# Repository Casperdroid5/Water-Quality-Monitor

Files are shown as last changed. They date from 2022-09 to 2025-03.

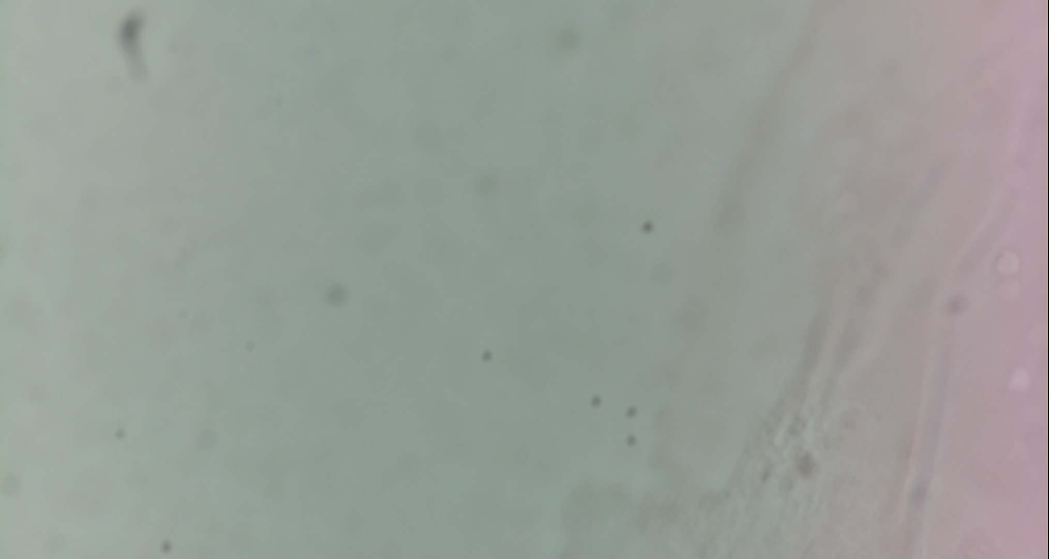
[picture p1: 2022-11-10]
Software/Camera/Test recordings/test.jpg

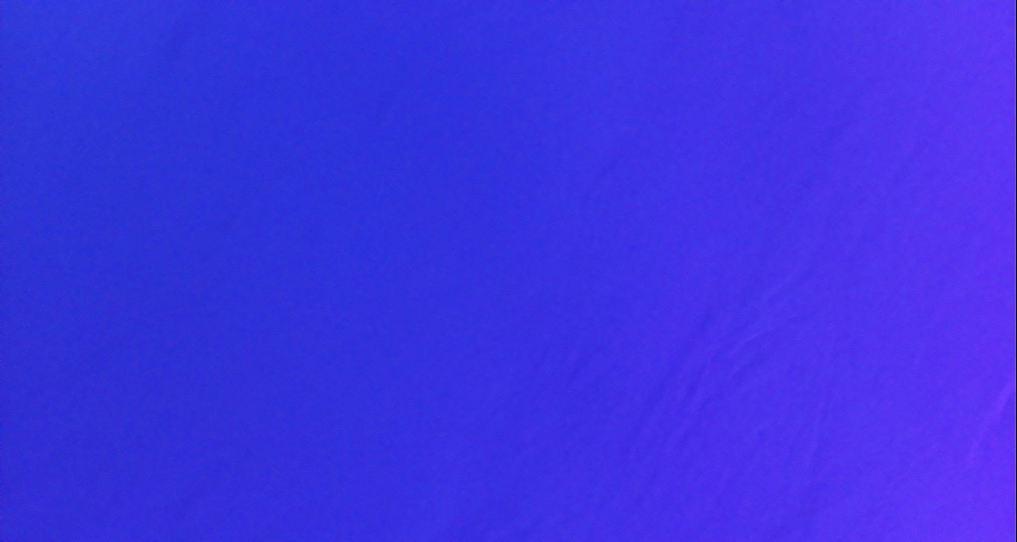
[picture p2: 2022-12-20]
Software/Camera/test3.jpg

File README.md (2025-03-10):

# Water Quality Monitor

This document outlines my contribution to the Water Quality Monitor project during my internship at the Health Concept Lab.

## Overview

The Water Quality Monitor utilizes a Raspberry Pi running Raspbian as the main controller and computer, along with a custom-designed PCB for circuit layout. Hardware control, GUI, and data processing are implemented using Python.

## Design Process

The design process involved selecting suitable hardware components, designing the PCB layout, and programming the firmware in Python.

1. **Hardware Selection**: Chose appropriate sensors, actuators, and electronic components to suit the needs of the clients setup.
2. **PCB Design**: Created a custom PCB layout to ensure optimal circuit connections.
3. **Firmware Development**: Developed the firmware using Python to enable hardware communication.
## Testing

Comprehensive testing was conducted to ensure accuracy and reliability.

1. **Hardware Testing**: Verified proper functionality of each hardware component on the printed circuitboard.
2. **Software Testing**: Thoroughly tested firmware for peripherals.

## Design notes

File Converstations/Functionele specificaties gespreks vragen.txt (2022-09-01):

1. Is dit een water kwaliteit monitor voor nu? -> het is een waterkwaliteit monitor
2. Hoe wordt de informatie gewonnen, via camera, maar hoe wordt dit geïnterpreteerd en in hoe verre is dit mijn taak? -> camera is belangrijkste, andere sensoren op i2c voor uitbreiding. ik hoef niet specifiek met de camera bezig. Beelden maken (foto's en video's) moet ik wel maken en verwerken. simpele foto of video maken door de microscoop, niets bijzonders verder.
3. De hoofdfunctie is water kwaliteit meten, maar wat zijn de subfuncties die deze hoofdfunctie in werking brengen?
4. Kunnen we samen gaan zitten voor de functionele specificaties?
5. Strokenplanner gebruiken, in combinatie met trello.
6. Na documentatie voor functioneel en technisch, blokdiagram maken (functie verbintenissen, input/ouput, power definities).

PCB functions: 
Doel voor camera: scherp beeld = Focus motor: driver, lens moet versteld worden of Moving magnet driver, voor scherpstellen/focus

Led driver voor camera verlichting (cn5711)

Pompmotor = driver voor pompmotor (misschien 3 motoren) één voegt water toe, ander stofje etc. 

Externe connectoren i2c (sparkfun connector molex?) 

Koelen en verhitten: moet flink wat stroom kunnen lopen (flinke kunnen stromen schakellen) 

Temperatuur sensor via i2c (al één gevonden) 
Flatcabel met daarin camera focusmotor stroom en i2c gecombineerd.

Één flatcable naar mijn printplaat (sensoren zijn i2c) 

Stepper motor chip (tmc2208)

Moving manget actuator driver (drv8838, vereist speciale pwm pinnen)

Hoofdvoeding wordt aangesloten aan mijn pcb, mijn pcb voedt de pi (v-in pin). 
Motoren en cool/warmte zal niet tegelijkertijd stroom verbruiken. Peltier verbruikt stroom terwijl sensoren meten.

Printplaat mag groter dan de pi (liever niet). Liefst 1 printplaat. Quad layer pcb.  Functionaliteit is belangrijk, hoeft niet draagbaar (wel optilbaar) te zijn (stroom)

Stacking pcb’s? flex pcb’s?

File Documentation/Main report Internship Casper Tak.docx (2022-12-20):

# POA Internship

Main report internship assignment Health Concept Lab

Student: Casper R. Tak

Studentnumber: 657313

Client: Rudie van den Heuvel

Coach: Jeroen Veen

High School: HAN Arnhem

Education: Embedded Systems Engineering

Date: 15-12-2022

# Preface

After attending both the S3 and S4 projects at the Health Concept Lab (HCL) at the HAN, I decided that this would also be a great place to do my internship. Since I have some learning goals left from my S4 project, I would like to finish those in my internship period. The goals I Have set are as follows:

- Improving and applying my planning skills to create more structure in my work approach
- Exploring and improving even further on PCB design by designing a PCB with KiCad V6
- Improving my programming basics and skills withing the language C, C++ and Python
- Explore and expand my horizon

The assignment that will allow me to get to these learning goals will be the fluid analysing device project. This project will focus on getting a better, smaller version of the fluid analysing device that was build by the S6 project students from previous years. The project is developed by Jeroen Veen, who is therefor my client.

This system will eventually be used as a mean to analyse water quality. Since people use a lot of medicine, especially since they get older and older, the urine and defecation contains medicine remains. This results in water getting polluted with these remains and that is harmful for organisms. The goals in the future will be to create a portable device that can easily and continuously monitor the water. Even further in the future the device will not only be used for fluid analysing but also recursive testing for (multiple) deceases.

# Motive

My interest in health and care have grown exponentially since my S3 project. I got interested in almost anything health care technology related. I got into contact with Rudie van den Heuvel, who told me that the health concept lab was still looking for students that could help with several project including the water monitoring system. He told me about the possibilities of growing with my PCB and Python skills and this is what got me motivated to join the HCL. I think the health concept lab and it teachers are able to provide me with the help and knowledge I seek to gain.

# Companies and individuals involved

Jeroen Veen is the project leader. He will be guiding me mostly through all the ESE related questions, regarding programming. Since Jeroen is the project leader and the client, I will be working very closely to him.

Rudie van den Heuvel is a IPD teacher and knows a lot about materials, mechanics and designing in general. He may be able to provide me with knowledge on how to approach this project and whenever I want to do something with materials, he can assist.

Health Concept Lab is the lab that has been created around 3 years ago. The goal of this lab is to create a pool of knowledge on health on both mechanical as electrical ground. The lab is populated by students from S3 and above and there some teachers, who are well known in the subjects, as well.

HAN teachers can be consulted as well. Johan Brussen or Francesco Ursino for example are well known with power electronics. They can help me when it comes to supplying bigger loads with power. Other ESE or ELC teachers can also be of help. For EMC I can probably go to Ivo van Diemen De Jel.

# Main and sub questions

The soul reason of creating this POA is to gain an understanding of the project, it’s size and the required approach to work as efficient as possible. By knowing what is expected, what is not, and how I think I can approach things, it should be possible for me to create a planning.

To get a understanding of the project’s size and the current challenges, I need to know what the problems are.

Problem: there is currently no all in one compact and functional driver board for the device.

# Goal and end product

The goal is to create a water analysing device. My goal would be to create a printed circuit board along with software for the raspberry pi that will control the monitoring system and retrieve all the data collected by it.

# Theory

See OneDrive documents.

I’m going to approach this project via the V-model

# Schedule

See schedule document.

# Design

Functional specifications
# | MoS CoW | Description

F1 | M | The device is collecting data with the biosensor setup
F1.1 | M | The device can detect particles
F1.2 | M | The device has a light source that provides sufficient light for the camera
F2 | M | The device can control the temperature of the examination chamber
F2.1 | M | The device can heat the examination chamber
F2.2 | M | The device can cool the examination chamber
F2.3 | M | The device can measure the temperature of the examination chamber
F3 | M | The device can manipulate fluid movement
F3.1.0 | M | The device can add fluids and remove fluids from the examination chamber
F3.1.1 | S | The fluid should be able to be moved forward and backwards.
F4 | M | The device is able to decontaminate the examination chamber
F5 | M | The device needs to be able to connect to external sensors
F6 | M | The device must be able to be carried by men
F6.1 | S | The device should be as small as possible
F6.2 | S | The device should be as light as possible
F6.3 | W | The device will not be battery powered

Technical Considerations
Part | (Expected) Function | Pros | Cons | Notes
Raspberry Pi 4 | Main computer | All in one computer, good documentation, good software support | Chip shortage creates vulnerability for supply chain | The compute model 4 is not an easy alternative since there is no build in camera connector. The Raspberry Pi 4 model B seems the most suitable
TPS61158 | LED driver | Flexible digital and pwm brightness control, 100:1 pwm dimming ratio, soft start build in | Datasheet unclear if there is a switching value of 750 Mhz or Khz | Mistakes in datasheet it seems, wrong frequency ratings
TPS6106x | LED driver | Pwm brightness control, digital brightness control, 1mhz fixed switching frequency | Made for multiple leds it seems, only 80% efficient | led disconnects during shutdown
TMC2209 | Stepper driver | High quality, good documentation | Not yet found, maybe over specked
ST L297 | Stepper driver | Reputable brand, low cpu usage | Expensive
Tmc2130 | Stepper driver | The flag ship version of the tmc series | Expensive and overkill
Tmc2208 | Stepper driver | Just as good as the 2209 | higher impedance and so lower output amperage than tmc2209. It also has less features than tmc2209
DRV8870 | H-bridge | Is able to supply 3.6A of current, enough for the peltier module most likely | Not the best option, a higher current version (6A) would have been ideal: DRV8874
IRL540SPBF | High load switching mosfet (logic level) | A logic level high mosfet that can handle very high currents (20A) | A little expensive
TPS61169 | LED driver | LED current can be set with resistor
TPS92360 | LED driver | LED current can be set with resistor | | Seems the same driver as the tps61169
P82B96 | I2C ESD protection IC | Galvanic separation of i2c lines which results in high esd level protection. One package saves all | A little more complicated possibly than using passive components. Expensive.

Technical specifications
# | MoSCoW | Description

T1 | M | A Raspberry Pi will be used as the computer and controller
T2 | M | The Raspberry Pi will connect to a PCB hat (PI-HAT)
T3 | M | The device will use a camera connected directly to the pi via a flat cable to take pictures and videos
T.3.1.0 | M | The camera will be stationary, the lens itself will move
T3.1.1 | M | The device will be able to focus and reposition the lens via motors or moving magnets
T3.1.2 | S | When using magnets, the drv8838 should be utilized
T4 | M | The device will have a LED to create light for the microscope
T4.1 | S | The led driver that should be utilized is the cn5711
T5 | M | There will be stepper motors used
T5.1 | S | The motors should be chosen according to the required strength
T5.2 | S | The motor resolution should be below x degrees
T6 | C | Some motors and sensors could be attachable via connectors
T6.1 | S | All connectors should be standard (nonproprietary)
T7 | M | The device will cool the examination chamber with a Peltier module
T7.1 | M | The Peltier module must be actively cooled to function and prevent damage
T7.2 | M | The device will heat the examination chamber via resistive heati
T8 | S | A flat cable should connect the sensors and motors data to the PI-HAT
T8.1 | C | The PI-Hat should distribute power to all devices including the Raspberry Pi
T8.2 | W | The PI-HAT will not have any LEDs or status indicators
T8.3 | C | The PI-HAT may provide a fan connector to cool the Raspberry Pi

# GUI

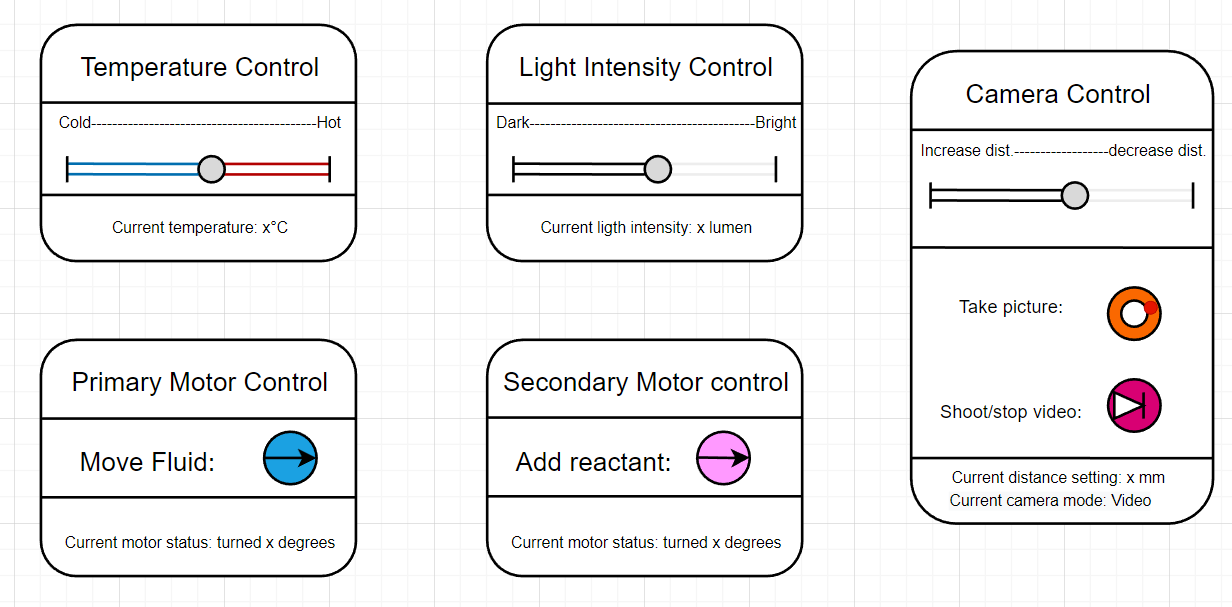
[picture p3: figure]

# Statemachine

State diagram

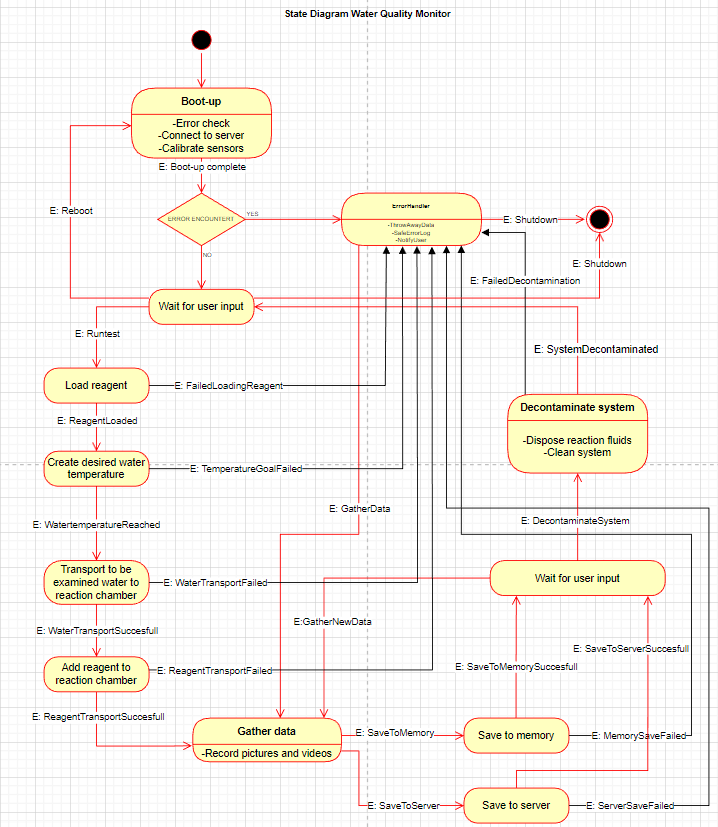
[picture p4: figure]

Use Case Diagram

System Architecture

Kesselring

# KiCad

## Why KiCad6?

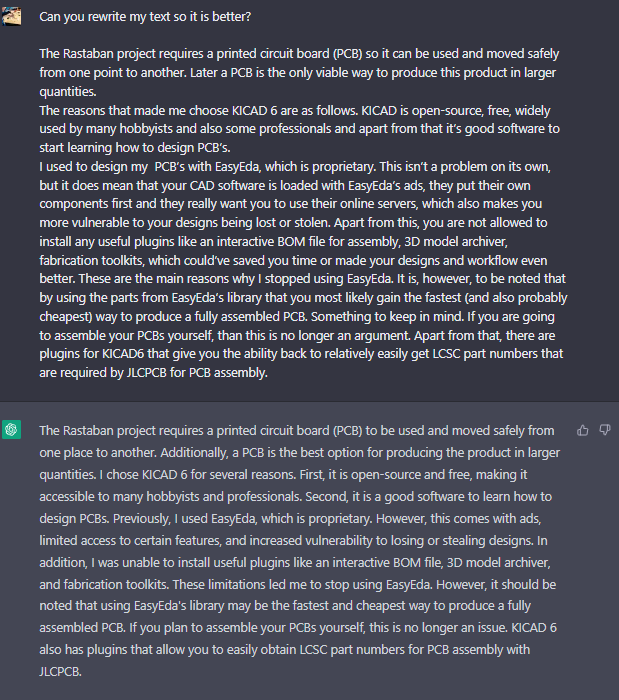
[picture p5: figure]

The Rastaban project requires a printed circuit board (PCB) to be used and moved safely from one place to another. Additionally, a PCB is the best option for producing the product in larger quantities. I chose KICAD 6 for several reasons.

First, it is open-source and free, making it accessible to many hobbyists and professionals. Second, it is a good software to learn how to design PCBs. Previously, I used EasyEda, which is proprietary. However, this comes with ads, limited access to certain features, and increased vulnerability to losing or stealing designs. In addition, I was unable to install useful plugins like an interactive BOM file, 3D model archiver, and fabrication toolkits. These limitations led me to stop using EasyEda. However, it should be noted that using EasyEda's library may be the fastest and cheapest way to produce a fully assembled PCB. If you plan to assemble your PCBs yourself, this is no longer an issue. KICAD 6 also has plugins that allow you to easily obtain LCSC part numbers for PCB assembly with JLCPCB.

## Plugins

To create an even better PCB and make my workflow easier, I downloaded a few plugins. The plugins I downloaded are as follows:

Name | Function | Download location
KiCAD JLCPCB tools | This plugin allows you to search the JLCPCB parts database, assign LCSC article numbers to your parts, generate production files for JLCPCB and much more. | https://github.com/Bouni/kicad-jlcpcb-tools
Interactive HTML BOM | This plugin generates convenient BOM listing with ability to visually correlate and easily search for components and their placements on the pcb. | Build into KICAD6
PCB action tools | Annular Ring Checker, Snap Selected Footprint(s) to Grid, Fabrication Footprint Position, Move Selected Drawings to chosen Layer, Export pcb technical layers to DXF, Checking 3D missing models | Build into KICAD6
Archive 3D models | Copies footprint models to the project local subfolder and remaps all the links within the used footprints. | Build into KICAD6
Place Footprints | Arrange sequentially numbered footprints or footprints from multiple hierarchical sheets in linear, circular or matrix arrangement. This plugin works on footprints already present in the layout, so that layout and schematics stay in sync. | Build into KICAD6
Round Tracks | Algorithmically smooth tracks in a predictable manner. Useful for flex PCBs, or just because it looks cool. | Build into KICAD6
Length matching | Track Length Calculator | Build into KICAD6
Freerouting | Auto router for Kicad. It draws all the connections between components for you. Be warned: Auto routing should never be used carelessly, always check the results. | Build into KICAD6 (requires Java)

## How to learn KICAD6

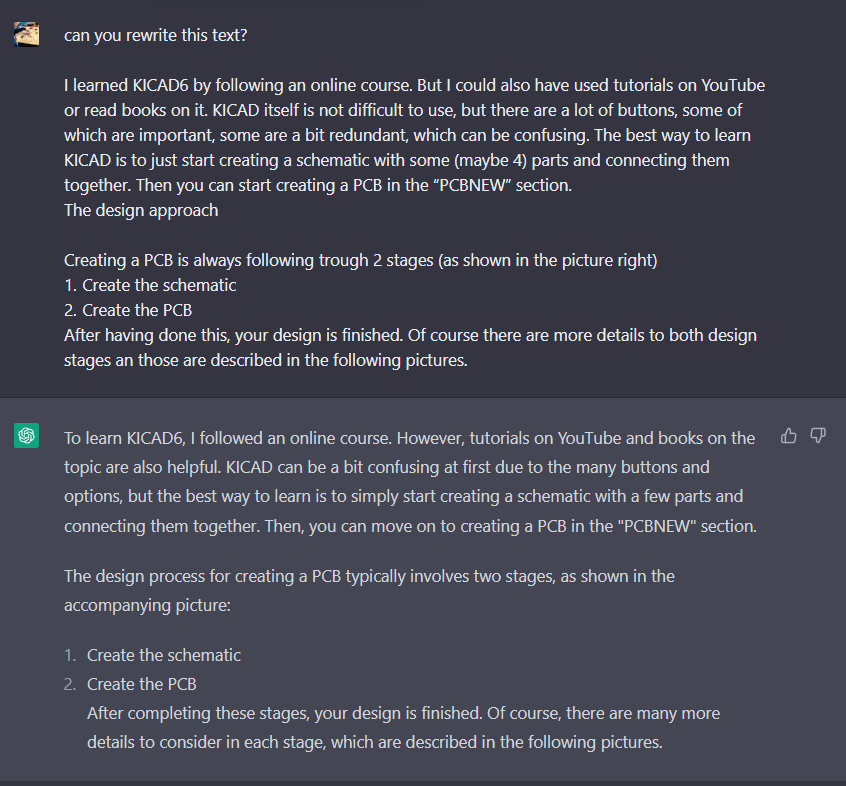
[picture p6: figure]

I learned KICAD6 by following an online course. (https://techexplorations.com/so/kicad-like-a-pro-3rd-edition/) But I could also have used tutorials on YouTube or read books on it. KICAD itself is not difficult to use, but there are a lot of buttons, some of which are important, some are a bit redundant, which can be confusing. The best way to learn KICAD is to just start creating a schematic with some (maybe 4) parts and connecting them together. Then you can start creating a PCB in the “PCBNEW” section.

## The design approach

Creating a PCB is always following trough 2 stages (as shown in the picture right)

1. Create the schematic

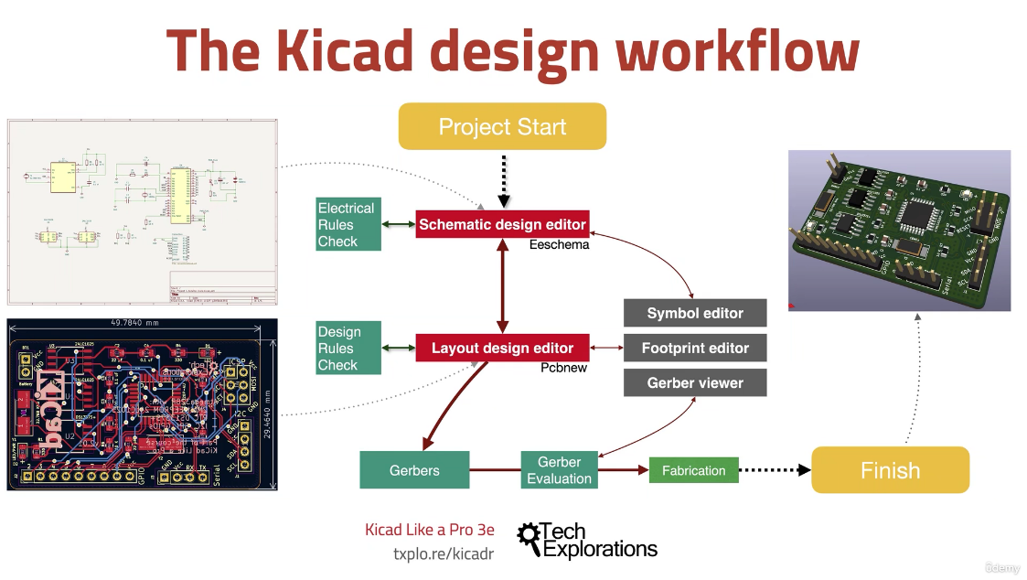
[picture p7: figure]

2. Create the PCB

After having done this, your design is finished. Of course there are more details to both design stages an those are described in the following pictures.

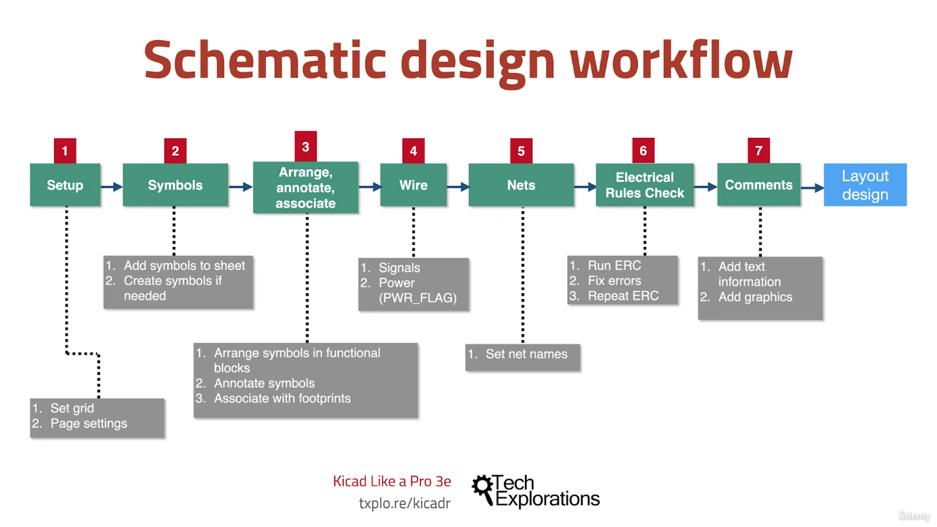
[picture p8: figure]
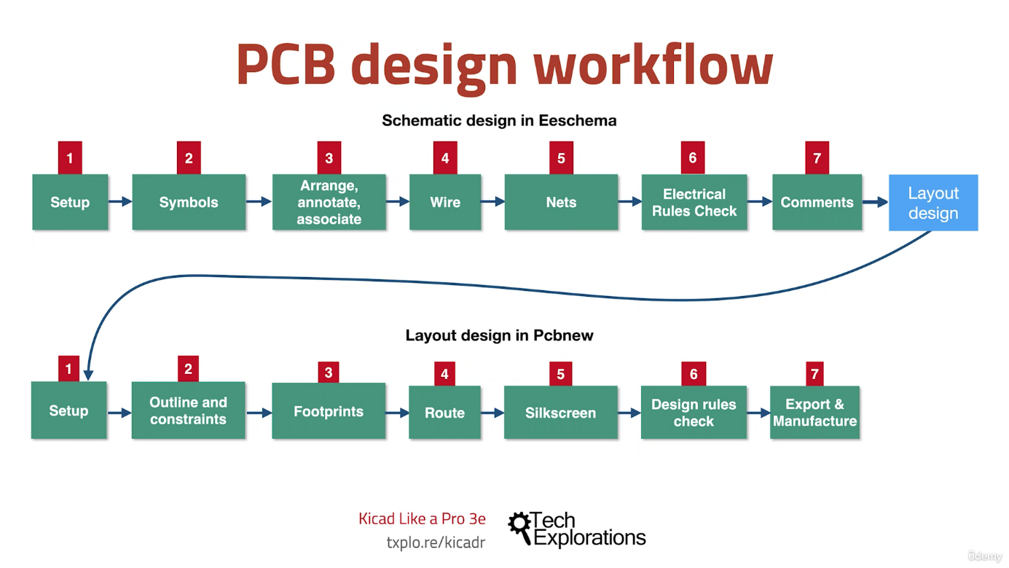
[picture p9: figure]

# System Components

## Microscope led

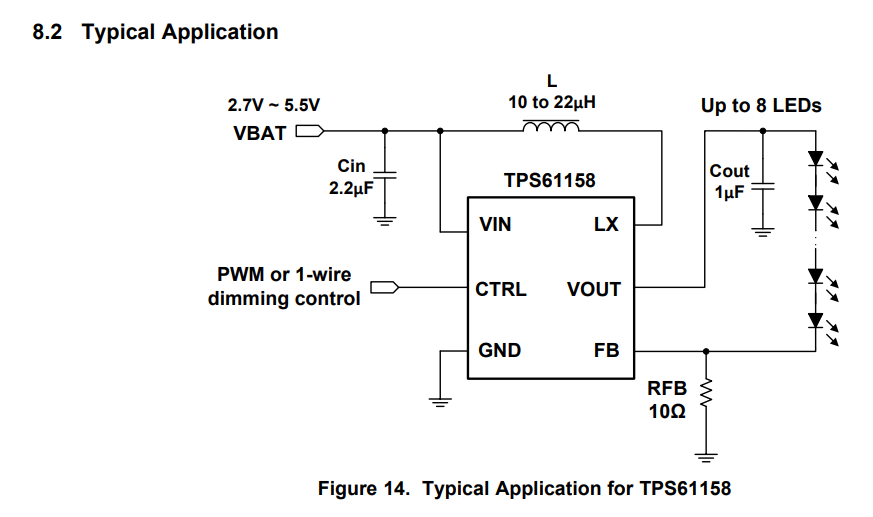
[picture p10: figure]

The input capacitor is to filter ripples from the power source and is there to function as a tiny buffer. The output capacitor is responsible for delivering current to the leds when the required current cannot be drawn continuously from the IC itself due to switching or power supply reasons. The inductor is there to function within the boost circuitry and has a high influence on the ripple and on maximum current and efficiency.

It is important to follow the pcb layout recommendations to avoid unsuspected behaviour due to unwanted resistance or capacitances.

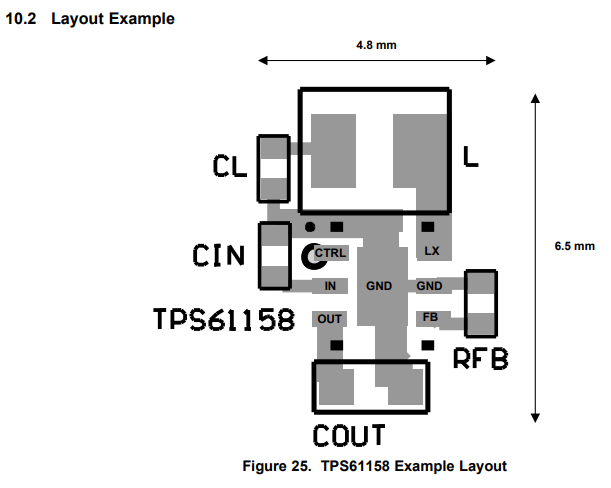
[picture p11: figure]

### Testing plan

When making a video or taking a picture of the reaction chamber, it is important that the LED light has a switching frequency that is higher than the shutter speed of the camera. If this is not the case, it could be that the image will appear to be darker or completely dark and that flickering will occur while recording a video. Therefor we need to know all shutter speeds of the camera and then we need to find what frequencies we need to drive the LED with, especially when dimming the light.

Our expected shutter speed: 60

Minimal shutter speed: 300usecs (https://forums.raspberrypi.com/viewtopic.php?t=323983)

Python control camera: https://raspberrypi.stackexchange.com/questions/99304/shutter-speed-and-exposure-time-of-picamera

About shutter speed and fps: https://camerajabber.com/what-shutter-speed-for-filming-moving-subjects/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,What%20is%20this%3F&text=Therefore%20if%20you%27re%20shooting,speed%20should%20be%201%2F120th.

## Driver circuit decision table

Nr. | Functionality | 1 | 2 | 3 | 4 | 5 | 6 | Points | Weightfactor
1 | Dim the led without visible flickering | - | 1 | 1 | 1 | 1 | 1 | 5 | 5
2 | Provide enough power to fully brighten LED | 0 | - | 0 | 1 | 1 | 1 | 3 | 3
3 | Enough brightness levels | 0 | 1 | - | 1 | 1 | 0 | 3 | 3
4 | PWM and digital control | 0 | 0 | 0 | - | 0 | 1 | 1 | 1
5 | PWM only control | 0 | 0 | 0 | 1 | - | 1 | 2 | 2
6 | Highest energy efficiency as possible | 0 | 0 | 0 | 0 | 0 | - | 0 | 0

We later concluded that it was rather difficult to get our hands on the chips we wanted to use. This is why we chose to go with the CN5711 driver. This one is widely available on LCSC, AliExpress and similar shops.

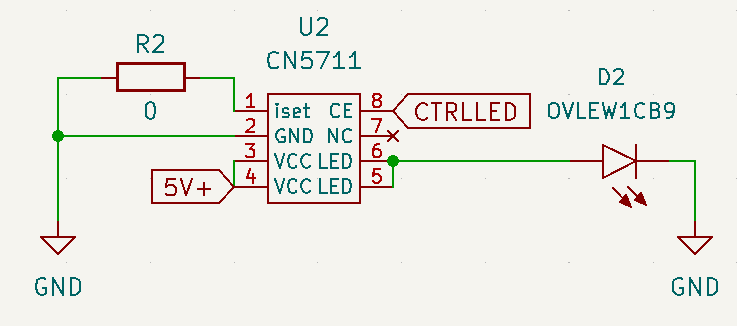
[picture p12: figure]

The driver was used in the testing setup for the LED. We never intended to use this chip since I didn’t feel comfortable investing in a “no name/brandless” chip that may become obsolete sooner than later. However for this prototype it is sufficient. Driving the chip is done via a PWM signal, which is not proprietary, the code will always stay the same even with a new driver. R2 may be set if current limiting the driver is desired.

## Stepper motor driver

2209 and 2208 have the same pinout, this should mean that they are interchangeable when it comes to the footprint on the pcb.

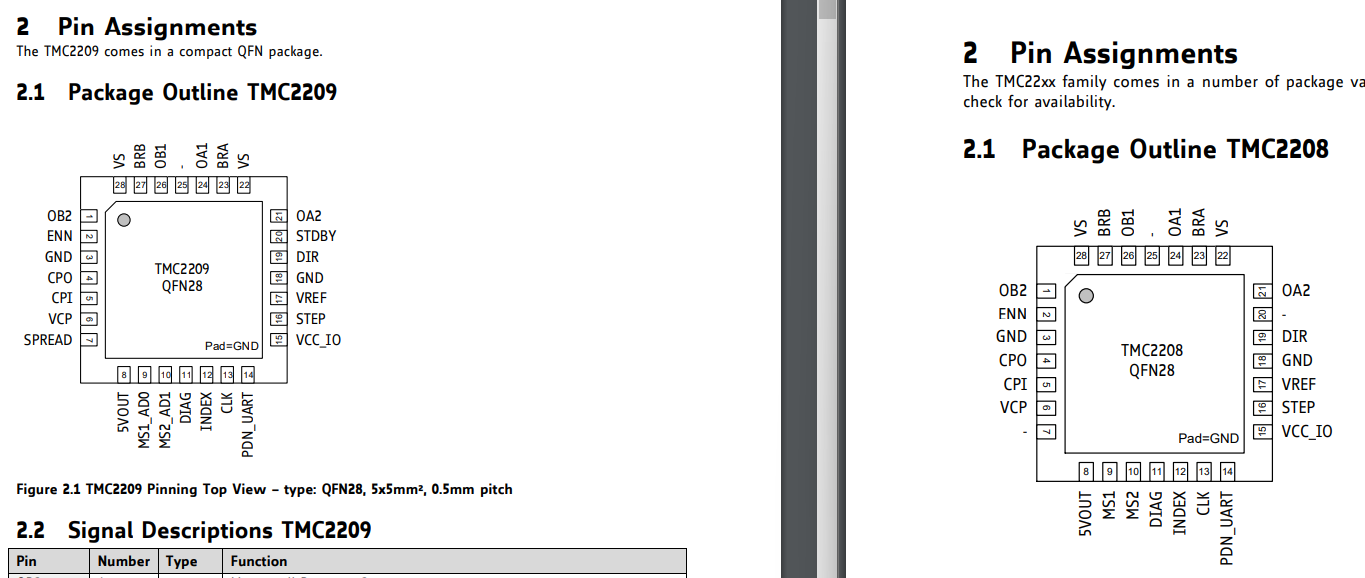
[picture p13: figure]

For layout considerations check chapter 19 of the tmc2208 datasheet.

### Later findings

The TMC2209 is the definitive replacement of the TMC2208 and TMC2130, so there is no good reason to keep using the depreciated TMC2208 in further designs.

### Micro stepping

Normally a stepper motor has 200 steps per complete revolution. Micro stepping can give you up to 51200 steps per complete revolution (depents on the motor of course) or 1/256 steps.

Benefits: improves noise levels and motor smoothness/accuracy and could improve energy effiency.

Drawbacks: decreases torque (especially at higher speeds) which could lead to stalling (some drivers can change stepping modes accordingly to speed).

source on Micro stepping https://www.youtube.com/watch?v=G8oGa2mawKk&t=68s

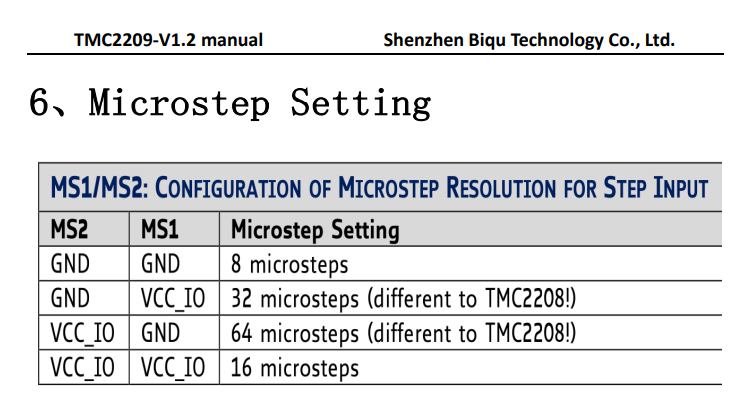
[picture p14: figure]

### UART on the TMC2209

Using the UART function of the TMC2209 we gain control many new functions including:

- Access to the control register
- Programmable 256 uStep sequencer
- Pulse generator
- SpreadCycle
- StealthChop
- Access to OTP

It is be possible to remove the STEP and DIR connections if we use UART to control one motor.

### UART Problem with multiple drivers

When connection multiple drivers you are able to read/write commands to the drivers individually using the same bidirectional line:

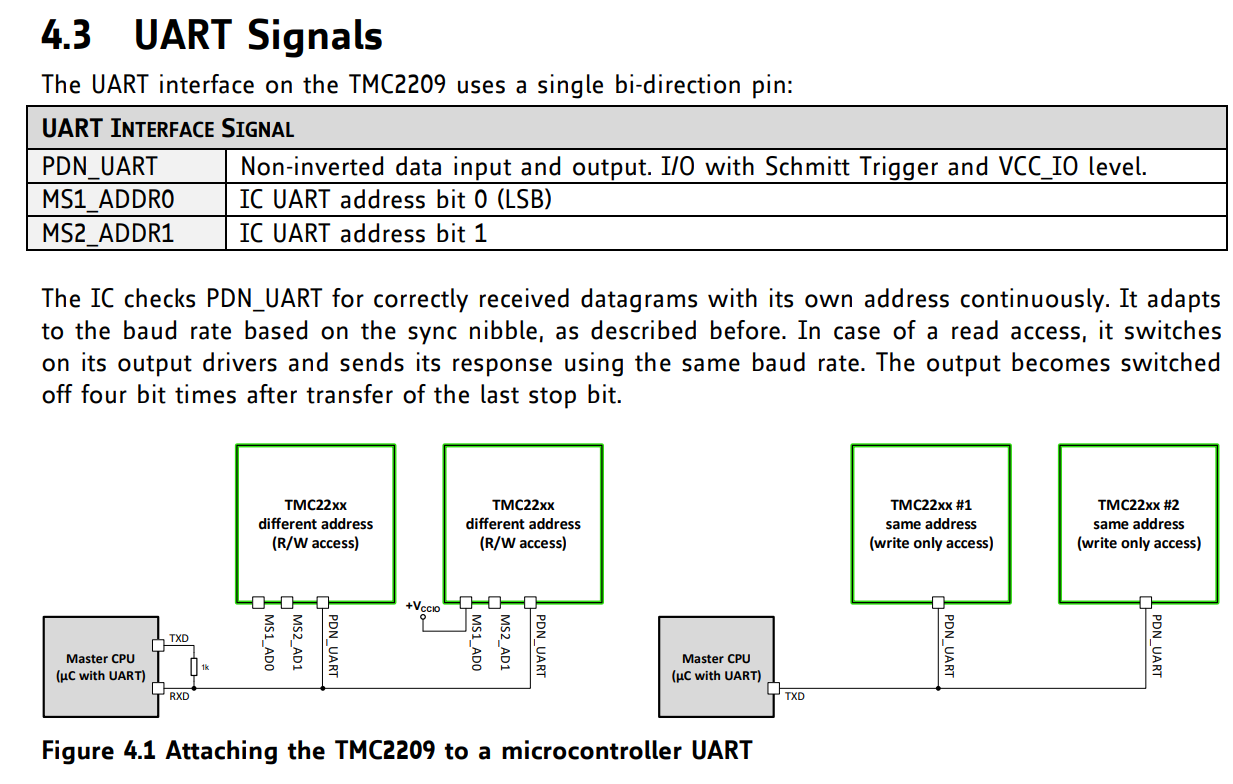
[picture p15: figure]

Strangely enough I not figure out why the above configuration did not work.

I configured one driver to be 01 and the other 00 by connection the ms1 and ms2 to GND and VCC the way it was shown in figure 4.1 above. Somehow I always get this message:

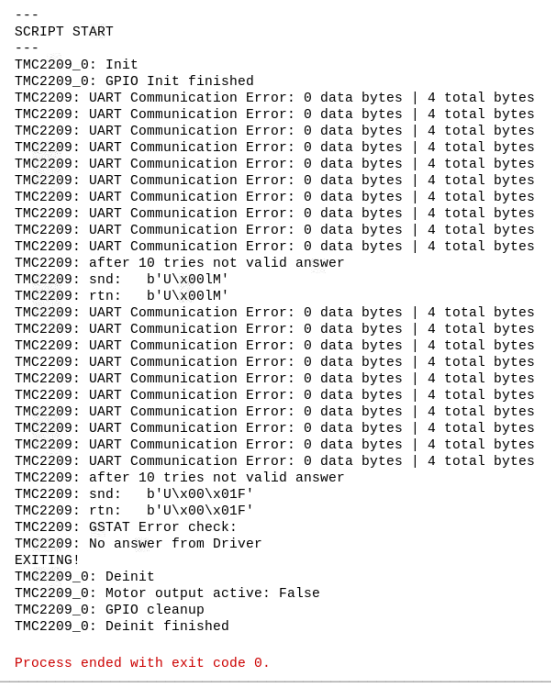
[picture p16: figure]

These are the configurations I tested:

| PDN UART | TMC software address settings | Result | Additional notes
TMC driver A | Connected to RX | 1 | Functional | Changing one address to 0 also makes it NOT functional
TMC driver B | Floating | 1
TMC driver A | Floating | 0 | Functional
TMC driver B | Connected to RX | 0
TMC driver A | Connected to RX | 0 | NOT Functional
TMC driver B | Floating | 1
TMC driver A | Floating | 0 | NOT Functional
TMC driver B | Connected to RX | 1

Conclusion: The driver UART control only works if there is one driver connected to RX and assigned address to this driver is selected in software (according to the ms1 + ms2 settings you chose). You can however use 2 drivers if you go with the “more than 4 drivers solution” which Trinamic provided. This could be achieved with transistors I suppose.

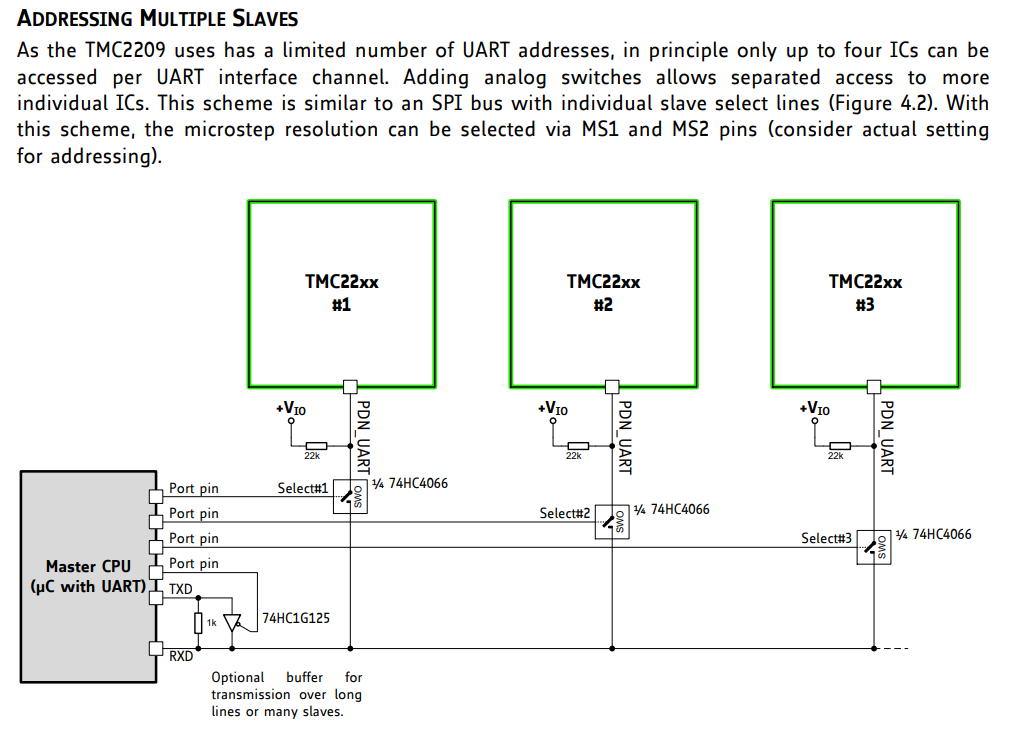
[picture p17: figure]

If reading from the driver is not required, using the write only function as seen in figure 4.1 of the datasheet is a viable option. This way we only need to use n+1 pins of the raspberry pi to control the motors, where n increases with every driver added (enable pin). This would treat all steppers as the same and would control them using the enable pin and sending data over the RX pin.

Configuration (test script 05: vactual.py) RX and TX are flipped on the picture:

This is what a successful transmission, with a few rotations and direction changes should look like.

When zoomed in it is clear that the TX deviates from the RX line data.

Further inspection shows that it does sometimes match the RX line

It is however always the case that TX continues sending after RX is done with a package.

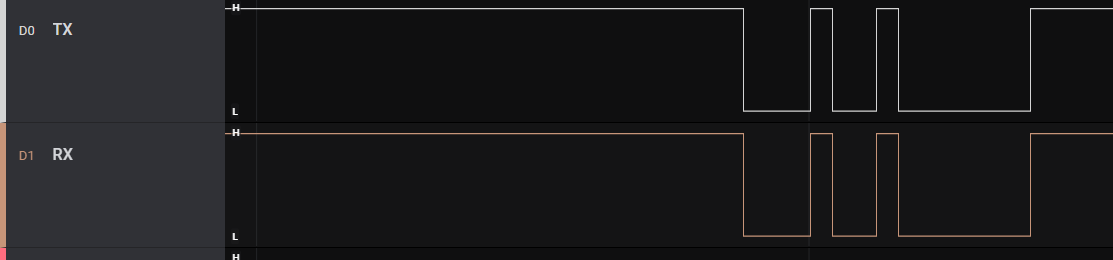
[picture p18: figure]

It is however always the case that TX continues sending after RX is done with a package.

Using these settings (test script 06: multiple drivers.py) RX and TX are flipped on the picture:

This is what a unsuccessful transmission looks like:

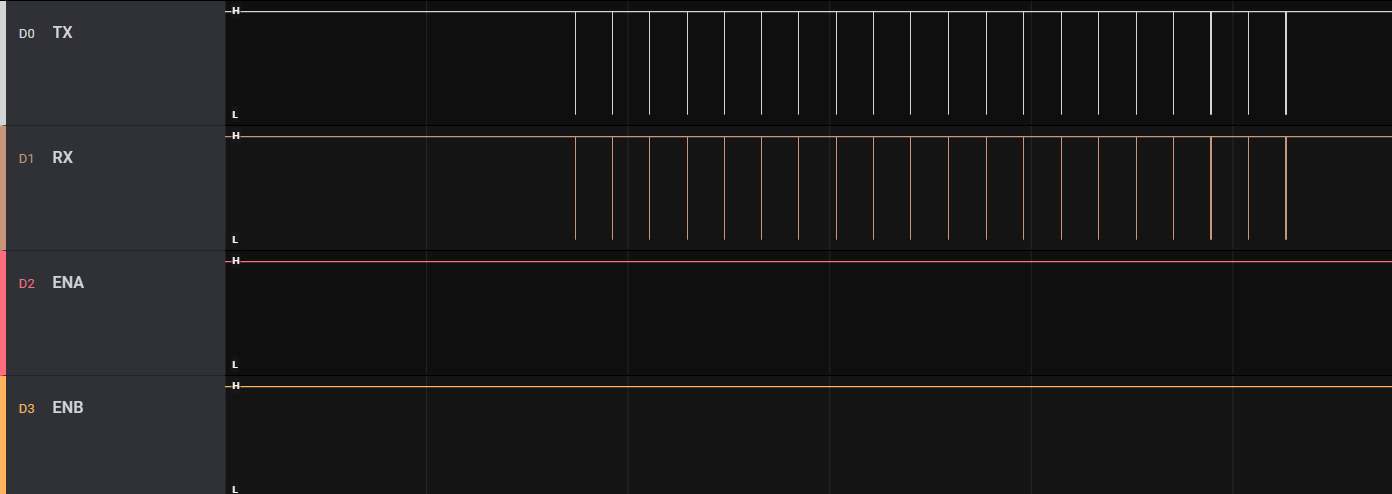
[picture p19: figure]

When zoomed in it seems that TX receives exactly the same information as it sends out. While, as stated earlier, it is expected that TX sends more data after RX is finished.

### Conclusion multiple drivers UART error:

I can conclude that somehow TX is getting the same information as it sends out on the RX line.

Fix found by Thomas Ijsseldijk: lowering the TX resistor to 500ohms increases the voltage available for the IO of the TMC driver which results in the TMC being able to read the signal. It appears to be very important to choose the right resistor value. It is now possible to control the stepper motors via UART. This reduces the pins required on the raspberry pi with 7 pins (removing all step and dir pins)

The final configuration for the stepper motor drivers is as following:

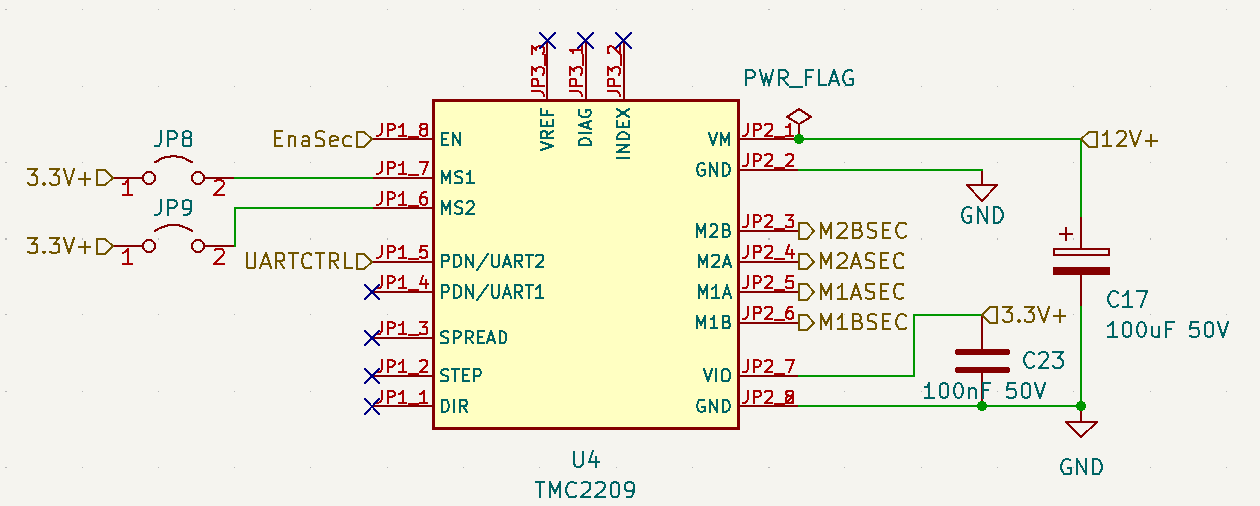
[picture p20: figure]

We decided to go with the TMC2209 and we operate it in UART mode only. This means we need to connect to PDN UART and use one enable pin per driver to select it.
Thermal Control

Thermal control will be in charge of providing energy and controlling all thermal regulating components of the Water Quality Monitoring (Rastaban) device fluids.

### The modules

The Thermal control consists of three power components:

1. Power Resistor
2. Peltier module
3. Fan (for peltier)

These components are here to increase or lower the temperature of fluid that would be examined. The first two modules will be drawing very high currents (2A and higher) and therefore these powerlines need to be controlled and protected with care.

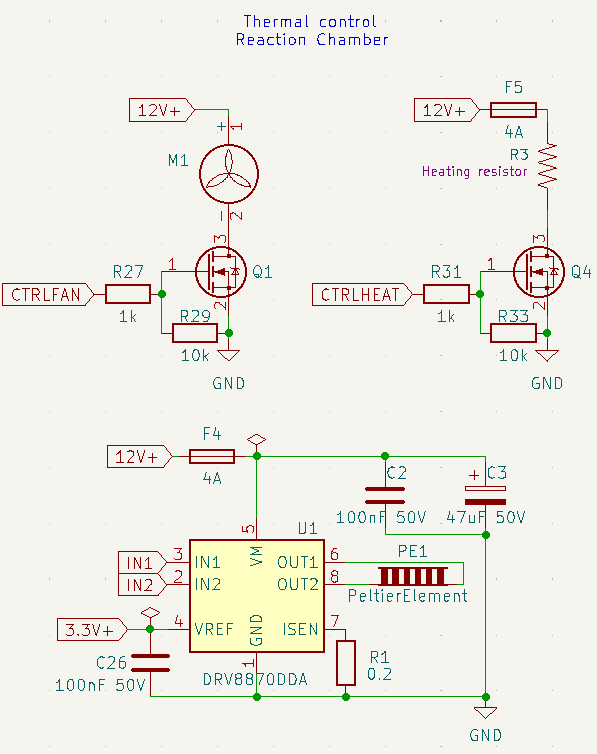
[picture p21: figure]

### The circuit

To control and protect the module and PCB from damage we need to building some passive protection. That’s why I chose some fuses that are roughly 1.25 times the value of the maximum current the module is supposed to use. When this value Is exceeded, the fuse will “blow” and the current will stop flowing.

The power mosfet used is the PMV15ENE. This NPN mosfet is designed to be controlled by a 3.3V logic level signal, which the raspberry pi uses as well. The mosfet is able to switch 6A and that’s why the component may seem overspecced. However, by using a higher current mosfet (lower RDS-on) there is higher efficiency because less energy is converted into resistive energy (heat). The component will also have a longer lifetime expectancy. Apart from this it also means there are no extra cooling components (heatsinks) required for this mosfet.

For the Peltier module we used a H-bridge since the Peltier module can cool or heat the same side when current is reversed. The module can help reaching higher temperatures in combination with the power resistor. When the current is reversed cooling the same surface can be achieved.

### EMC

EMC or electromagnetic compatibility is a significant part of every PCB design. We don’t want the high currents that flow through these components to disrupt the signals lines. Therefore I need to consider the position of the power wires.

## PowerManagementSystem

The PowerManagementSystem (PMS) will be in charge of providing energy to all components of the Water Quality Monitoring device (Rastaban). The device has the following components that require power:

### Power Supply

This table is just an indication of the possible power consumption and it was made to give some insights. After seeing this table I think I can conclude that a 24V 10A (240W) power supply should be sufficient to run the whole device at full power, something that will not be typical but should be accounted for. This power supply will be an external one for the time being, since it eliminates the need for a much bigger PCB and extra EMC and safety precautions. It also gives us the possibility to easily swap the PSU out if it gets damaged.

### Preventing Noise

It is important to prevent noise that may be caused by some more power hungry components in the device. That’s the reason why I will try create power lines for 12V, 5.0V and 3.3V. The 12V rail will use a lot of power where the 5.0V and 3.3V are on the lower side of power usage. The use of capacitors will also smooth out the voltage dips that may occur while load becomes high.

### Planes on PCB

There are multiple benefits to using ground planes, something that is already widely known. It improves thermals for heat inducing chips and it helps preventing EMC issues. It may however be wise to keep analog and digital grounds separated, to prevent ground loops and the noise it creates. We may use positive 12V or 5.2V planes as well, so we can transfer high currents to some loads without heating up the PCB, but this may introduce interference (EMC) with signal lines, something that is not tolerable.

Later in the project we figured that it is not possible to keep analog and digital grounds separated, since some ic’s have analog inputs ground that are connected to digital ground. If even one ic has this ground setup, than trying to separate the grounds won’t work. Adding the face that it makes routing the pcb more difficult, we will keep this idea in mind, but we won’t implement it for now.

### EMC

EMC or electromagnetic compatibility is a significant part of every PCB design. This starts at the schematic level by making sure there are enough decoupling capacitors, 0 ohm star grounding and keeping HIGH power LOW power, digital and analog circuits as isolated as possible.

### ESD protection

A typical voltage clamping diode circuit is shown below. The main responsibility of this voltage clamping circuit is to limit the accumulation of voltages on the input terminal of the buffer. Note that this could also be applied to the differential input on an op-amp. The operation of this circuit is very simple and, under normal conditions, diodes D1 and D2 are reverse biased. Whenever the voltage at the input is larger than the supply rail voltage, then diode D1 is forward biased and conducts. Similarly, when the voltage at the input falls below ground, then diode D2 is forward biased and conducts from the ground towards the input. This circuit seems to be suitable for at least the i2c data lines in our design.

We later decided to implement this, since we can always leave the diodes out on the PCB if it may not be necessary after all.

### Power regulators

There a two main types of upping or lowering the voltage in a circuit. We can use Buck/Boost converters or linear regulators. The main benefit of using a buck/boost converter is its high efficiency and therefor lower heat dissipation. Sadly it comes at the price of many components (PCB space) and a noise on the supply line due to switching. A linear regulator on the other hand wastes an extreme amount of the energy supplied to it as heat, but the output voltage does not create as much noise. A great bonus is that if the voltage difference is not great between input and output, than sometimes the linear regulator is more efficient than a switching.

Choosing what type fits our voltage rails really depends on what is more important in our device’s case. We care more about functionality and repairability at this stage of the device so using a linear regulator would most likely be sufficient in most of our cases.

We later decided to go with two step down converters. We use switching regulators: one for the raspberry pi 5.0V, which can deliver 3A max if required. This is smart since the RPI will later use a camera. Some other components run on the same 5V as the raspberry pi like the microscope led, the voicecoil driver (with buck converter IC) and it is also supplying the 5.0V breakout of the breakout power pins header. There is most likely no protection required since the LM2596 5.0 has build in thermal and overvoltage protection. The 3.3V converters are the TLV1117-33 ic’s. These can provide up to 3A.

### 12V vs 24V

Since the primary and secondary stepper motors are designed to run on 12V we think it may be wise to choose a 12V supply. 24V gives us more headroom for voltage dips, but the motors can probably not handle the voltage difference. It is also less efficient to buck a higher voltage to a lower voltage, so keeping the difference lower is better. We do need to compensate for the possible voltage dips with capacitors and a PSU with a rather high current (probably 10A). I think that a 120W power supply would suffice for this prototype. As an addition we found that the peltier module usually work on lower voltages like 12V, 5.0V and even 2.2V when they are really small (1cm by 1cm). bucking the voltage from 24 to 12 or lower and still having >3A currents will be very difficult when it comes to sizes of IC’s. using 12V is again beneficial in this case.

### Trace width

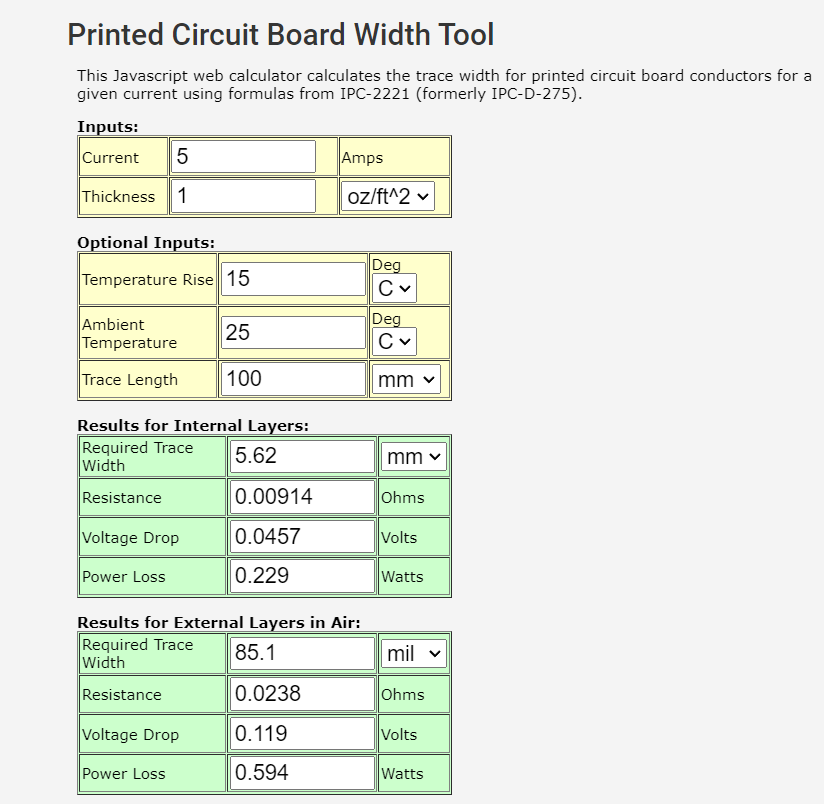
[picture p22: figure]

Since high currents will run through the board to some components, we need to create thicker wires other wise the resistance will be too high and the board will heat drastically, possibly leading to traces burning up or degrading over time due to temperature fluctuations.

I used an online calculator to get a overall indication of the track width required. Sadly it seems impossible to create a 5.62 mm trace for every high power net. I decided to go with a trace with that was still possible to route and that roughly resembled the width of the package pins of the power ic use. This may not have the most professional way to test and see if this would work, but it is the only way to go. It later seemed to work perfectly fine using 0.6mm wide traces. It would be a smart experiment to check the temperature of the board with a high resolution thermal camera.

### Coil whine

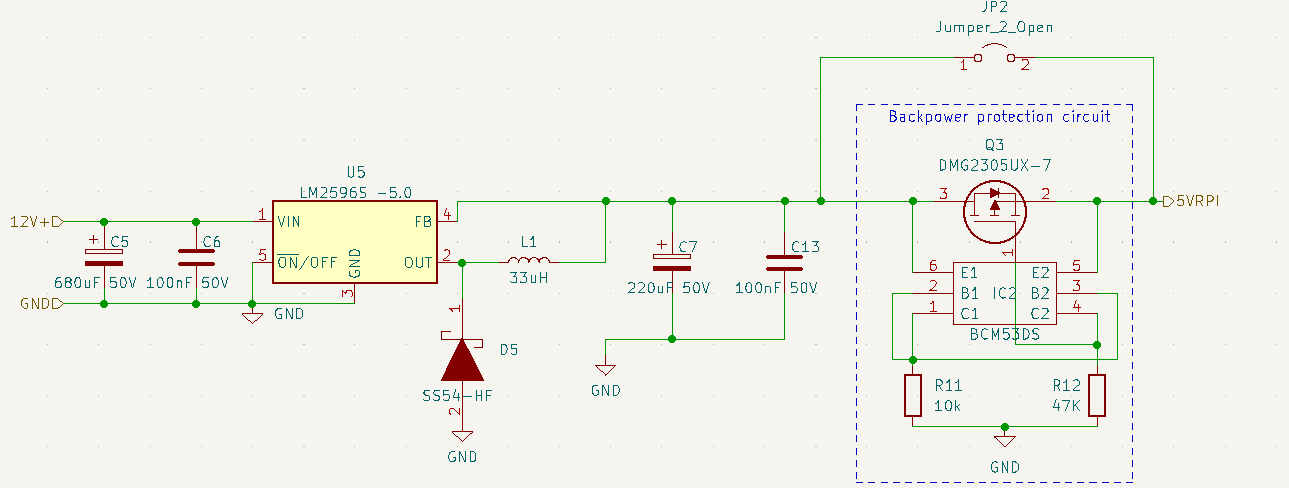
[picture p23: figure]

I noticed that the power circuit created a high whining noise when I connected a minor load (300ma). This noise was most likely coming from the coil. I forgot to add the decoupling capacitor to the output of the LM2596 5.0. This most likely caused the output to create pulses in the kHz range that where audible trough the coil.

It was resolved after adding an 220uF capacitor to the output.

### Backpower protection circuit

The Backpower protection circuit or BPC is there to protect the Raspberry pi if the user connects a 5V supply to the raspberry pi micro usb port and connects 12V to the barrel jack on the pi hat at the same time. This circuit was not tested since we lacked the components required to create it. The protection circuit can be bypassed using the solder jumper JP2. The housing for the Rastaban project could be designed in such a way that the micro usb connector gets covered.

## Pi Hat i2c EEPROM interface

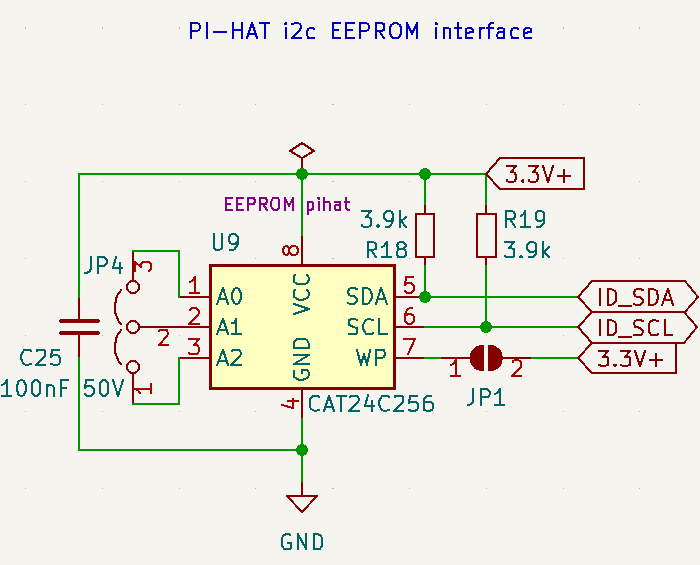
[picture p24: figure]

The i2c EEPROM interface is to create a script that sets the RPI in “rastaban mode”. The sense hat, made by the raspberry pi foundation, uses the eeprom to identify the sense hat version and id in the software used for the hat. This way it is possible for the rpi to recognize different hats and react accordingly by setting the right settings, running the right code etc.

We later realised that this may be unnecessary since we program the SD Card to work with this hat specifically and there will not be any other boards required. Maybe this i2c eeprom chip can be reused for safer data logging storage. The micro SD card tents to get corrupt in raspberry pi’s after reading and especially writing many times.

## 12V POWER GPIO

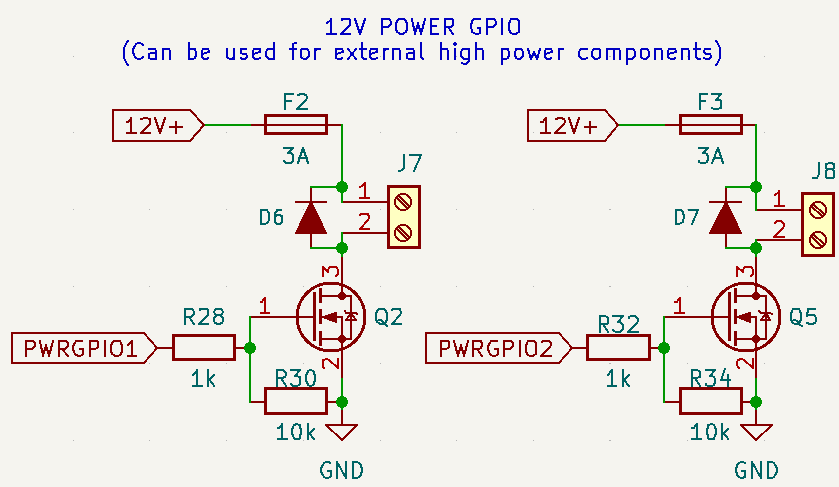
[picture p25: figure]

I added two power outputs for the user to connect high power loads to. The devices could theoretically draw to up to 6A, but I limited the fuses to 3A and the loads should be chosen accordingly or controlled with PWM to avoid tripping the fuse. The diodes are there to prevent back EMF destroying the mosfet or 12V supply when suddenly disconnecting an inductive load such as an motor. The 1k resistor on the pwrgpio pin is for ESD protection of the pin and the 10k resistor is to define a state fo the mosfet at all times even if the raspberry pi is disconnected physically.

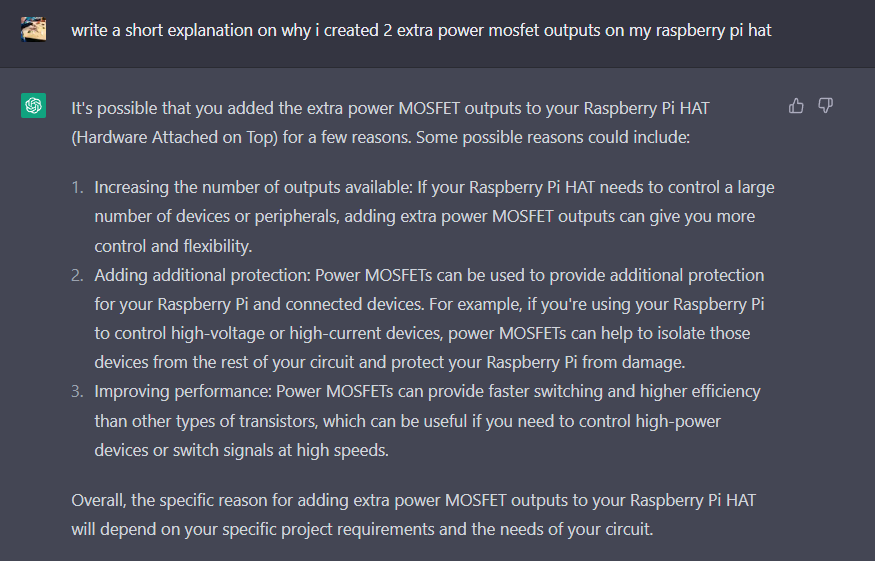
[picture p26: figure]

This prevents a floating pin and therefor unpredictable behaviour.

## Focus motors

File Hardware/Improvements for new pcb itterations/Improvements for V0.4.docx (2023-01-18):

Improvements for V0.4 of the Rastaban PCB

# | Improvement/note | Implemented/finished

1 | Make the H-bridge compatible with different Peltier module sizes (different voltages)
2 | Possibly breakout more gpio pins
3 | Watch out for PEO connector on rpi (keep out zone possibly) R2 is now touching the PEO connector.
4 | Heater and micled are behind the usb port of the pi, this is not an option. Next time load in raspberry pi 3D model to catch this issue beforehand. Move connectors or use vertical connectors (easier). For now it is possible to move the hat a bit more up using a taller header or an extender possibly.
5 | Write insertion methode for module like the drv8838 and the tmc2209 driver boards (to avoid reversed polarity)
6 | The I2c port should be vertical one as well to keep this small profile board.
7 | It is possible to apply D4 and D1 footprints for D7 and D6 (smaller footprints)
8 | CPU heatsink cannot be placed because of components on bottom side of PCB
9 | Anode cathode of Diodes may be misleading. The “C” is not always the way the diode should be pointed to (D5, D3)

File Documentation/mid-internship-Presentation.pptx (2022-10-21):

## Stage Casper Tak

## Het Rastaban project

- Introductie project
- Proces
- Plannen voor de toekomst
- Afsluiting

## Introductie project

- Achtergrond
- Vorige groepen
- Het doel (nu, toekomst)

## Proces

- PCB
  - Doel
    - KICAD6
    - Pluggins
- Software
  - Doel
    - PyQt
    - GUI
    - Qt functies

## Plannen voor de toekomst

- Water kwaliteit monitor
  - toekomst
- DNA
  - toekomst

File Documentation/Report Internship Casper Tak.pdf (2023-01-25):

# Designing and producing a test platform for fluid monitoring


Redesigning a fluid monitoring setup’s hardware and software for increased functionality, reliability, and durability.

Internship documentation
Embedded Systems Engineering

# Casper R. Tak

## 1 General Information

Document
Version: V1.0
Date: 24-01-2023
Word count: 17166
Page count main report: 47 Page count attachments: 21

Student
Name: Casper R. Tak
Studentnumber: 657313
Email: cr.tak@student.han.nl Phone number: 0612292537

Institution
High School: Hogeschool van Arnhem en Nijmegen (HAN)
Faculty: Academic Engineering and Automotive (AEA)
Education: Embedded Systems Engineering (ESE)
Start and end of internship: 1 September 2022 until 27 January 2023

Client
Name: Jeroen Veen
Email: jeroen.veen@han.nl

Coaches
Name: Rudie van den Heuvel Email: R.vandenheuvel@han.nl

Name: Jeroen Veen
Email: jeroen.veen@han.nl

Source logo HAN (Wikipedia)
All illustrations are self made unless specifically mentioned

## 2 Document log

Table 1 Document history

Version | Date | Edits/notes
1.0 | 25-01-2023 | Finalized main report. Changed cover photo.
0.4 | 25-01-2023 | Incorporated Jeroen’s feedback on V0.2 added hyperlinks for some figures and tables. Added word count and page count.
0.3 | 24-01-2023 | Added reflection, added results and overall improvements.
0.2 | 23-01-2023 | Many edits done. Added front page and incorporated most of Jeroen’s feedback on V0.1.
0.1 | 09-01-2023 | Start of report laid down basic layout and style.

## 3 Summary

In this report, I present the hardware and software design and implementation of the Rastaban water quality monitoring system.

The system uses a Raspberry Pi running Raspbian as the main controller and computer, and a PCB for circuit layout. Control of the hardware, GUI, and data processing is done using Python. The design process involved selecting suitable hardware, designing the PCB, and programming the firmware in Python. The system was tested to ensure accurate and reliable measurements by testing both hardware and software components separately.

## 4 Introduction

This document is written for my client, Jeroen Veen and potentially others (students) who want in insight in my journey to creating the hardware for the so called Rastaban project where fluids like water are being monitored. This document contains my design path from software and hardware for my Rastaban PCB.

I wrote this document for my embedded systems internship at the HCL. I have always had my interests in technology and this became apparent when I was little. I always moved trains and gears to see how the worked. I disassembled many, many devices, like Gameboys, Mixers, DVD players etc. I also broke many by doing so. Learning how to repair devices and what component does what was one of the things that I wanted to know when I was in middle school. After that finding an education that could teach me that and teach me how to create my own devices became my goal. I later found a small job as a care taker of elderly people and found so many subjects where machines could assist them in their lives. That’s how I found myself in my first project in the HCL and after 2 projects I still wanted more health related projects. That’s how I ended in the HCL for my internship.

While working on this project I have learned so much when it comes to general improvements in my design course. I used the V-model as a guideline for the first time and I found that it really helped me stay on track. I also found that I improved my scheduling and log skills. Apart from that I have developed myself by exploring different subjects like industrial product designing and even teaching and coaching ESE and IPD students.

I want to thank Jeroen Veen for all his hard work and patience when teaching me how to approach this project and teaching me about software and hardware. I know that Jeroen and I do not always think or communicate the same way and that sometimes resulted in misunderstanding, but I found this challenging and an excellent exercise. Thankfully, we also could fantasize and discuss very interesting subjects like morals on some technical aspects and I think we learned a thing or two from each other by doing so. I really enjoyed that. I think that Jeroen and I can be a real brainstorm machine sometimes and I hope that we can one day.

Rudie van den Heuvel was (on paper) my client, but we quickly figured that the WQM was a more suitable project for me and that was fine. Rudie helped me very much by talking about some more personal subjects like human-human relationships and how to communicate with people who are different. He sometimes thought me a lot by saying nothing at all. I learned from his positive mindset and wise stickers and quotes. When teaching the IPD students I saw how Rudie approached his students and this was inspiring to me. I really hope that Rudie and I will be working together in the future, maybe IPD related?

# List of contents

# List of tables

# List of figures

# Glossary

Rastaban name of the current prototype that is being developed (PI HAT)

HAT An attachment for the Raspberry Pi 40 pin connector header. Usually consists of specific hardware for a specific task like a 3d printing HAT.

# Acronyms

WQM Water quality monitor

PCB Printed Circuit board, a thin board that provides footprints and wires for electrical components to be connected to.

RPI Raspberry Pi

IPD/IDE Industrial product design(er) or Industrial Design Engineer(ing)

ESE Embedded Systems Engineer(ing)

PMS Power management system

ESD Electrostatic discharge

IC Integrated circuit

PWM Pulse width modulation

## 5 Preface

### 5.1 Personal Goals

I recently completed projects S3 and S4 at the Health Concept Lab (HCL) at the HAN and decided to do my internship at the same location. During my internship, I plan to further develop my planning skills and improve my PCB design skills using KiCad6. Additionally, I hope to improve my programming skills in C, C++, and Python. I am also interested in exploring and expanding my knowledge and understanding of various topics like industrial product design.

The fluid analyzing device project will be a key part of my internship as it will allow me to achieve these learning goals. The project involves creating a smaller, improved version of a fluid analyzing device that was developed by previous S6 and S4 students. The device is being developed for Jeroen Veen, who is the client for this project. I will later write a reflection where I will conclude if I achieved my goals.

### 5.2 Personal Motivation

My interest in health and care has grown significantly since completing my S3 project. I have become interested in anything related to health care technology. I was fortunate enough to come into contact with Rudie van den Heuvel, who informed me that the Health Concept Lab (HCL) was still seeking students to assist with various projects, including a water monitoring system. Rudie mentioned the opportunity to grow my PCB and Python skills, which motivated me to join the HCL. I believe that the HCL and its teachers can provide me with the support and knowledge I am seeking to gain.

## 6 Background information

### 6.1 Water quality monitoring background

The ultimate goal of this system is to analyze and monitor water quality. As people age and take more medications, the remains of these medications can end up in urine and feces, leading to polluted water that can harm organisms. The Water Quality Monitor (WQM) will be a relatively cheap and useful device to use for testing the quality of water or other fluids. For now the focus is on water but the long-term goal is to create a portable device that can continuously monitor water quality and potentially even test for diseases.

### 6.2 Stakeholders

Jeroen Veen is the project leader. He will be guiding me mostly through all the ESE related questions, regarding programming, but also regarding the overall process and development skills. Since Jeroen is the project leader and the client, I will be working very closely to him.

Rudie van den Heuvel is an industrial product design (IPD) teacher and knows a lot about materials, mechanics and designing in general. He may be able to provide me with knowledge on how to approach this project and whenever I want to do something with materials, he can assist.

Health Concept Lab is the lab that has been created around 3 years ago. The goal of this lab is to create a pool of knowledge on health on both mechanical as electrical ground. The lab is populated by students from S3 and above and there some teachers, who are well known in the subjects, as well.

HAN teachers can be consulted as well. Johan Brussen or Francesco Ursino for example are well known with power electronics. They can help me when it comes to supplying bigger loads with power. Other ESE or ELT teachers can also be of help. For EMC I can probably go to Ico van Diemen De Jel.

## 7 Main and sub questions

In this paragraph I will list everything I need to know to get this project started. I need a basic understanding of the project, it’s size and the required approach to work as efficient as possible. By knowing what is expected, what is not, and how I think I can approach problems, it should be possible for me to create an approach plan.

1. Main: What is the goal of this product?
2. Main: What will be my contribution to this project?
a. Sub: What do I think is achievable in this timespan?
3. Main: What is water quality?
a. Sub: how can we measure water quality?
4. Main: What is the current process on this project
a. Sub: what did previous groups contribute?
b. Sub: what can be used or build upon in my project?

Answers:

1. The goal is to create a prototype within 5 months that is able to monitor water quality.
2. I will be designing and creating this prototype’s hardware and software.
a. I think designing a PCB in combination with software that controls it should be possible.
3. Water quality is measured by several factors, such as the concentration of dissolved oxygen, bacteria levels, the amount of salt (or salinity), or the amount of material suspended in the water (turbidity). In some bodies of water, the concentration of microscopic algae and quantities of pesticides, herbicides, heavy metals, and other contaminants may also be measured to determine water quality. (Sanctuary, 2023)
a. Water quality parameters include chemical, physical, and biological properties and can be tested or monitored based on the desired water parameters of concern. Parameters that are frequently sampled or monitored for water quality include temperature, dissolved oxygen, pH, conductivity, ORP, and turbidity. However water monitoring may also include measuring total algae, ISEs (ammonia, nitrate, chloride), or laboratory parameters such as BOD, titration, or TOC. (YSI, 2023)
4. The previous groups have presented prototypes and Jeroen Veen has created some software himself to control some aspects of the WQM.
a. The previous groups S4 and the S6, have contributed by designing PCBs and software for the WQM. S4 has focused on making the control board that can be attached to the raspberry pi. The raspberry pi would use a camera attachment and a microscope to observe water quality. The S4 setup was relatively small, but also limited in its functionality. The S6 group has created a fully functioning setup with heaters, pumps for (precision) fluid movement and a spectrometer. They focused on this sensor instead of a camera attachment for the pi. Sadly the setup is rather large, prone to getting detached cables, since not everything is soldered and its control interface is not intuitive. The problem the client is now facing in short: the current prototypes lack in functionality, are prone failing hardware problems or they are not easily controlled.
b. I think I can build upon the work of both groups. I should consider some of the choices they made. Connector types, software libraries, components etc. Maybe I find that some of their design choices are a good starting point for my project or I find that it can better be archived and I will create my own design. I do know that I would like to work on the idea of a HAT (attachable PCB for the pi)

## 8 Objective and end product

The goal is to design and develop a stable and sturdy prototype device, called Rastaban, for monitoring water quality. The device will be equipped with a printed circuit board (PCB), we will call this the HAT. Further there will be software created for the Raspberry Pi and this PCB, which will control the whole system and retrieve data collected by it.

Rastaban is a project that aims to improve water quality monitoring in various locations. The device will be used to monitor water quality by taking optical images and videos of the chemical reaction that emerges when a water sample is mixed with the reaction fluid in the reaction chamber.

The device will be used by environmental scientists, engineers, students from the Wageningen University and other professionals who are interested in monitoring and improving water quality. The device should be able to operate in a range of aquatic environments, including freshwater and saltwater. It should also be durable enough to withstand harsh weather conditions and rough handling.

The project will be divided into several phases, including research and development, prototyping, testing, and deployment. We aim to complete the first compact Rastaban prototype within the next 5 months. The first version of the Rastaban will be designed and developed specifically for measuring water quality. However, we will also keep DNA research capabilities in mind during the design process, and incorporate any necessary components or features suggested by Jeroen.

My contribution to this project will be the design and creation of the HAT and it’s software to control it. After this period I deliver the hardware, software and documents. This way the device will be usable, expendable and serviceable by anyone with basic knowledge on the subject.

## 9 Functional Design

Before creating anything, as the V-model shows, it is important to gather specifications. I started by creating a list of functional specifications: what should the device be able to do? Should it be able to move fluids? Should it be able to heat up the fluids? Etc. These specifications will be the guideline to follow while making decisions. The goal is to create a sturdy device that will be used for monitoring water quality. The basic input/output of the WQM will be as follows:

Figure 1 Input output diagram

### 9.1 State machine

The device will mostly be working in this continuous simplified manner.

1. Prepare system for testing (flush system clean, reach required fluid temperature etc.).
2. When the fluids are ready, pump them to the reaction chamber for measuring.
3. Capture optical images/video’s.
4. Store the captured data on a storage medium or cloud-based storage.


Figure 2 State machine

## 9.2 Use Case Diagram

In the use case diagram we show the normal usage of the system in a static way. Here it is explained how the system functions in a block and how to Actor (user) provides input to the WQM and how the WQM may come in contact with a server solution.


Figure 3 Use Case Diagram

### 9.3 State diagram

To make this device usable for now and in the foreseen future, there will be functional and technical requirements that reflect this. For example, the device may later be used as an DNA monitoring device, and that requires heating and cooling elements in the reaction chamber to function.

Therefore some specifications will be chosen for future use accordingly. But to know how a WQM would work and what specifications are required, we need to know its usual operation style. Therefore, I created a simple state diagram.

This diagram gives the overall view of how the state machine will work if Rastaban would be used in the field, functioning automatically or if it would be controlled manually.


Figure 4 State diagram

After having created the diagrams indicating the expected functionality required by the WQM, I created a list with functional specifications.

Table 2 Functional specifications

Functional specifications

# | MoS CoW | Description

F1 | M | The device is collecting data with the biosensor setup
F1.1 | M | The device can detect particles
F1.2 | M | The device has a light source that provides sufficient light for the camera
F2 | M | The device can control the temperature of the examination chamber
F2.1 | M | The device can heat the examination chamber
F2.2 | M | The device can cool the examination chamber
F2.3 | M | The device can measure the temperature of the examination chamber
F3 | M | The device can manipulate fluid movement
F3.1.0 | M | The device can add fluids and remove fluids from the examination chamber
F3.1.1 | S | The fluid should be able to be moved forward and backwards.
F4 | M | The device needs to be able to connect to external sensors
F5 | M | The device must be portable
F6 | W | The device will not be battery powered
F7 | C | The device could have Its own identification
F8 | M | The device must be sturdy
F8.1 | M | The device must be able to be moved without connections between electrical components being lost (lose cables)
F8.2 | S | The device should be protected against ESD to some extend
F8.3 | S | The device should have some EMC precautions

## 10 Technical design

After finishing the functional specifications, it is now possible to create a technical design upon our needs. The technical design is still inconclusive. I have to read datasheets to conclude what components are suitable for our prototype. My technical considerations can be found in Appendix C: Technical Considerations.

A technical design shows the technical requirements and specifications that must be met in order to ensure that the system performs as expected.

### 10.1 System architecture

The system architecture gives a static view of how the system components are connected to each other.

Figure 5 System Architecture

Table 3 Technical specifications

The technical design is elaborated no further in chapter 13: Hardware. There I will show in detail the hardware choices that have been made.

Technical specifications

# | MoSCoW | Description

T1 | M | A Raspberry Pi will be used as the computer and controller
T2 | M | The Raspberry Pi will connect to a PCB hat (PI-HAT)
T3 | M | The device will use a camera connected directly to the pi via a flat cable to take pictures and videos
T.3.1.0 | M | The camera will be stationary, the lens itself will move
T3.1.1 | M | The device will be able to focus and reposition the lens via motors or moving magnets (voice coil)
T3.1.2 | S | When using magnets (voice coil), the drv8838 should be utilized
T4 | M | The device will have a LED to create light for the microscope
T4.1 | S | The led driver that should be utilized is the cn5711
T5 | M | There will be stepper motors used
T5.1 | S | The motors should be chosen according to the required strength
T5.2 | S | The motor resolution should be below x degrees
T6 | C | Some motors and sensors could be attachable via connectors
T6.1 | S | All connectors should be standard (nonproprietary)
T7 | M | The device will cool the examination chamber with a Peltier module
T7.1 | M | The Peltier module must be actively cooled to function and prevent damage
T7.2 | M | The device will heat the examination chamber via resistive heating
T8 | C | A flat cable could be used to connect the data lines and power to the PI-HAT
T8.1 | S | The PI-Hat should distribute power to all devices including the Raspberry Pi
T8.2 | W | The PI-HAT will not have any LEDs or status indicators
T8.3 | C | The PI-HAT may provide a fan connector to cool the Raspberry Pi

## 11 Hardware

The Rastaban hardware consists of multiple components and categories. It controls, light intensity, temperature, movement and it has room for other sensors and output. All hardware will be described below.

### 11.1 Microscope led

The microscope led is the light source required for
the camera to see an image in the reaction chamber. One of the options for driving the led was the TPS61158 driver.


In this typical application circuit the input capacitor is to filter ripples from the power source and is there to function as a tiny buffer. The output capacitor is responsible for delivering current to the leds when the required current cannot be drawn continuously from the IC itself due to switching or power supply reasons. The inductor is there to function within the
boost circuitry and has a high influence on the ripple
and on maximum current and efficiency.

It is recommended to take advice from the pcb layout recommendations to avoid unsuspected behavior due to unwanted resistance or capacitances.

However most of the component placements are common rules for PCB layout, so this layout recommendation can be considered trivial.

We later concluded that it was rather
difficult to get our hands on the chips we
wanted to use. This is why we chose to go | with
the CN5711 driver. This one is widely
available on LCSC, AliExpress and similar
shops.
The driver was used in the testing setup for | the
LED. We never intended to use this chip | since
I didn’t feel comfortable investing in a “no
name/brandless” chip that may become obsolete sooner than later. However, for this prototype it is sufficient. Driving the chip is done via a PWM signal, which is not proprietary, the code will always stay the same even with a new driver. R2 may be set if current limiting the driver is desired.

Figure 6 Typical application TPS61158 driver

Figure 7 pcb recommendations

Figure 8 finalized led driver circuit.

11.1.1 Testing plan
In order to accurately capture images or videos of the reaction chamber, it is essential that the LED light used has a switching frequency that is higher than the camera's shutter speed. If the switching frequency is lower than the shutter speed, the resulting image or video may appear dark or flickering due to the incomplete exposure of the image sensor. To avoid this issue, it is necessary to determine the shutter speeds of the camera and select an appropriate LED switching frequency, particularly when dimming the light. This will ensure that the image or video is accurately captured with minimal artifacts.

Due to time limitations and other priorities I decided that testing this extensively is not smart. I tested the led by using a raspberry pi camera and my smartphone’s high speed camera starting a video capture and started dimming the led. I saw no direct flickering issues at most frequencies. I suspect that by further tweaking of the shutter speed of led switching frequencies it is possible to get even better results.

### 11.2 Stepper motor drivers

There are many different stepper driver models available. Since we opt to go for a compact PCB and since we don’t need to supply high currents it is safe to say that industrial grade or high current drivers aren’t going to be suitable for us. There are small drivers like the like the A4988 or the DRV8425 which are very simple to control and do not have any special functions except for micro stepping (Max 16uSteps). When searching for drivers, I found that 3D printing stepper drivers are very capable and well tested and documented by the community. So I found the TMC2208 and the TMC2209 stepper drivers.

The TMC2209 and TMC2208 are both stepper motor drivers that have identical pinouts, meaning they can be used interchangeably in terms of their physical footprint on a printed circuit board (PCB). For considerations regarding PCB layout, refer to Chapter 19 of the TMC2208 datasheet. It should be noted, however, that the TMC2209 is the recommended replacement for the TMC2208 and TMC2130 in newer designs, as it is the more current and up-to-date version of these drivers.

A typical stepper motor operates at a resolution of 200 steps per complete revolution. Through the use of micro stepping, the resolution of a stepper motor can be increased to as many as 51200 steps per revolution (depending on the specific motor). This results in a resolution of 1/256 steps. The implementation of micro stepping has been shown to reduce noise levels, improve the smoothness and accuracy of motor operation, and potentially increase energy efficiency. It is worth noting, however, that micro stepping can also decrease torque, particularly at higher speeds, which may lead to stalling. Some drivers are equipped with the ability to adjust the stepping mode based on speed in order to mitigate this issue.

Source on Micro stepping https://www.youtube.com/watch?v=G8oGa2mawKk&t=68s


Figure 9 Micro stepping settings table

11.2.1 UART on the TMC2209
The UART (Universal Asynchronous Receiver/Transmitter) interface is a serial communication protocol that allows for the transfer of data between devices. The TMC2209 stepper motor driver supports UART communication in addition to the traditional step/dir interface. Using UART to communicate with the TMC2209 can provide several benefits compared to using step/dir:
- Higher data transfer rates: UART allows for faster data transfer compared to step/dir, which can be useful for applications that require high-speed communication or precise control of the motor.
- More flexible control: UART allows for more advanced control of the motor, such as micro stepping, automatic load compensation, and stealthChop mode. These features are not available using the step/dir interface.
- Enhanced diagnostics and monitoring: UART allows for the monitoring of various internal parameters of the TMC2209, such as the temperature and current draw, which can be useful for debugging and performance optimization.
- Ease of use: UART can be easier to implement than step/dir, as it does not require the use of external pulse generators or counters.
- Using UART also removes the connection needed to step/dir. Using one RX line per driver and an enable pin to select the driver (with our current tmc2209 software).

Overall, using UART to communicate with the TMC2209 can provide improved performance, flexibility, and ease of use compared to using the step/dir interface. That’s why I settled for using this driver as our main stepper motor driver.

### 11.3 Thermal Control

Thermal control will be in charge of providing energy and controlling all thermal regulating components of the Water Quality Monitoring (Rastaban) device fluids.

11.3.1 The modules
The Thermal control consists of three power components:
1. Power Resistor
2. Peltier module
3. Fan (for Peltier)

These components are here to increase or lower the temperature of fluid that would be examined. The first two modules will be drawing very high currents (2A and higher) and therefore these powerlines need to be controlled and protected with care.


11.3.2 Schematics
To control and protect the module and PCB from damage
we need to building some passive protection. That’s why I chose some fuses that are roughly 1.25 times the value of the maximum current the module is supposed to use. When this value Is exceeded, the fuse will “blow” and the current will stop flowing.

The power mosfet used is the PMV15ENE. This NPN mosfet is designed to be controlled by a 3.3V logic level signal, which the raspberry pi uses as well. The mosfet is able to switch 6A and that’s why the component may seem overspecced. However, by using a higher current mosfet (lower RDS-on) there is higher efficiency because less energy is converted into resistive energy (heat). The component will also have a longer lifetime expectancy. Apart from this it also means there are no extra cooling components (heatsinks) required for this mosfet.

For the Peltier module we used a H-bridge since the Peltier module can cool or heat the same side when current is
reversed. The module can help reaching higher
temperatures in combination with the power resistor.
When the current is reversed cooling the same surface can be achieved.

Figure 10 Thermal control components circuit

### 11.4 Pi Hat i2c EEPROM interface

The i2c EEPROM interface was intended to create a script that would set the Raspberry Pi (RPI) in "Rastaban mode." The Sense Hat, developed by the Raspberry Pi Foundation, uses the EEPROM to identify the Sense Hat version and ID in the software used for the Hat. This allows the RPI to recognize different Hats and adjust settings, run appropriate code, and so on accordingly.

However, we later realized that this may be unnecessary as we are programming the SD card to work specifically with this Hat and there will not be a need to support other boards. It is possible that the i2c EEPROM chip could be repurposed for safer data logging storage, as micro SD cards tend to become corrupt in RPI systems after extensive reading and writing.

### 11.5 12V Power GPIO

I added two power outputs for the user to connect high power loads to. The devices could theoretically draw to up to 6A, but I limited the fuses to 3A and the loads should be chosen accordingly or controlled with PWM to avoid tripping the fuse. The diodes are there to prevent back EMF destroying the mosfet or 12V supply when suddenly disconnecting an inductive load such as an motor. The 1k resistor on the PWRGPIO pin is for ESD protection of the pin and the 10k resistor is to define a state for the mosfet at all
times even if the raspberry pi is disconnected
physically.

This prevents a floating pin and therefor unpredictable behavior.

Figure 11 optional EEPROM circuit

Figure 12 PowerGPIO circuit

### 11.6 PowerManagementSystem

The PowerManagementSystem (PMS) will be in charge of providing energy to all components of the Water Quality Monitoring (Rastaban). Rastaban has the following components that require power:

11.6.1 Power Supply
This table is just an indication of the maximum power rating and it was made to give some insights. After seeing this table I think I can conclude that a 24V 10A (240W) power supply should be sufficient to run the device when it’s working in its normal consumption parameters. I don’t see the device ever drawing 11Amps. This power supply will be an external one for the time being, since it eliminates the need for a much bigger PCB and extra EMC and safety precautions. It also gives us the possibility to easily swap the PSU out if it gets damaged.

11.6.2 Preventing Supply Noise
It is important to prevent noise that may be caused by some more power-hungry components in the device. That’s the reason why I will try create power lines for 12V, 5.0V and 3.3V. The 12V rail will use a lot of power where the 5.0V and 3.3V are on the lower side of power usage. The use of capacitors will also smooth out the voltage dips that may occur while load becomes high.

11.6.2.1 Planes on PCB
There are multiple benefits to using ground planes, something that is already widely known. It improves thermals for heat inducing chips and it helps preventing EMC issues. It may however be wise to keep analog and digital grounds separated, to prevent ground loops and the noise it creates. We may use positive 12V or 5.0V planes as well, so we can transfer high currents to some loads without heating up the PCB, but this may introduce interference (EMC) with signal lines, something that is not tolerable.

Later in the project we figured that it is not possible to keep analog and digital grounds separated, since some ics have analog inputs ground that are connected to digital ground. If even one ic has this ground setup, than trying to separate the grounds won’t work. Adding the face that it makes routing the pcb more difficult, we will keep this idea in mind, but we won’t implement it for now. It is not smart to use 12V high power planes on the pcb since this can create magnetic fields that interrupt data lines or components.

Component | Quantity | Max Voltage (V) | Max Current (A) | Max Power (W) | Notes
Raspberry Pi 4B | 1 | 5.2 | 3 | 15.6
Peltier Module | 1 | 12 | 4 | 48
Microscope LED | 1 | 3.2 | 0.05 | 0.16
Focussing lens motor driver | 3 | 12 | 2 | 24 | Unknown Stepper motor
Stepper motor driver | 3 | 12 | 2 | 24
TOTALS: | 9 | 44.4 | 11.05 | 111.76
Table 4 Estimated maximum power usage

11.6.3 EMC
EMC (Electromagnetic Compatibility) refers to the ability of electronic devices and systems to function properly in their intended electromagnetic environment without causing interference to other devices or systems. In the context of PCB (Printed Circuit Board) design, EMC refers to the design practices and measures that are taken to ensure that a PCB does not emit or receive electromagnetic interference (EMI) that could affect the performance or reliability of other electronic devices. There are several strategies that can be used to prevent unwanted EMC issues on a PCB:
1. Use proper grounding: Proper grounding is essential for EMC compliance. Use a solid ground plane and ensure that all ground connections are made as direct and low-impedance as possible.
2. Use proper power distribution: Proper power distribution helps to prevent voltage drops and noise on the power supply lines, which can cause EMI. Use a dedicated power plane and ensure that the power supply lines have low impedance.
3. Use proper decoupling: Decoupling capacitors help to filter out noise on the power supply lines and should be placed as close as possible to the power pins of all active components.
4. Use shielded components: Shielded components, such as shielded inductors and transformers, can help to reduce EMI.
5. Use proper routing: Proper routing helps to reduce the length and proximity of high-frequency signals, which can reduce EMI. Use a differential pair routing technique for high-speed signals and avoid routing signals near sensitive components or traces.

By following these design practices, it is possible to prevent unwanted EMC issues on a PCB and ensure that the electronic system functions properly in its intended environment. I have tried to implement a few of these strategies like point 1, 3 and possibly 5 if the pcb size allows this. Some strategies are not viable, cost effective or mandatory to get the system working properly.

I used a ground plane on the front and back of all my 2 layer PCB designs. This makes connecting al ground connections easier but I suspect it also creates a “shield” for underlaying layers when using 4 layer PCB’s where the second layer is a ground layer. I further made sure that my coil for the buck converter is properly shielded with the same ground plane and I routed no data lines beneath the coil. Since the coil produces an electric magnetic field it is wise to do so.

11.6.4 ESD protection
A voltage clamping diode circuit is used to prevent
excessive voltages from accumulating at the input terminal of a buffer or differential input of an operational amplifier (op-amp). The circuit consists of two diodes, D1 and D2, which are reverse-biased under normal conditions. When the input voltage exceeds the supply rail voltage, D1 becomes forward-biased and conducts, limiting the voltage at the input. Similarly, when the input voltage falls below ground, D2 becomes forward-biased and conducts, again limiting the voltage at the input. This circuit is useful for protecting sensitive input stages, such as those found on I2C data lines.

We later decided to implement this, as we can always omit the diodes on the PCB if it may not be necessary after all.

Figure 13 ESD protection using TVS diodes

11.6.5 Power regulators
There are two main methods for adjusting the voltage in a circuit: Buck/Boost converters and linear regulators. Buck/Boost converters are more efficient and produce less heat, but they require more components and can cause noise on the supply line due to switching. Linear regulators, on the other hand, waste a lot of energy as heat but produce less noise on the output voltage. However, in cases where the difference between the input and output voltage is not significant, linear regulators can be more efficient than switching regulators. The choice between these two options depends on the specific requirements of the device. In this case, we prioritize functionality and repairability, so we would likely choose a linear regulator. We ultimately decided to use two step-down converters, both of which are switching
regulators. The first one is used to power the
Raspberry Pi at 5.0V and can deliver up to 3A if needed. I chose this because the Raspberry Pi will eventually be used with a camera and that can
lead to higher current usage when compared
to using just the raspberry without peripherals.

Other components that also run on 5.0V, such as the microscope LED and the voice coil driver (with a buck converter IC), are powered by this converter as well. The 5.0V converter also supplies the 5.0V breakout of the breakout power pin header. It is unlikely that protection will be necessary, as the LM2596 5.0 has built-in thermal and overvoltage protection. The second converter is used to provide 3.3V and is based on the TLV1117-33 IC, which can deliver up to 3A. The output of this converter is connected to the voice coil motor driver (DRV8838).

11.6.6 12V vs 24V
Since the primary and secondary stepper motors are designed to run on 12V we think it may be wise to choose a 12V supply. 24V gives us more headroom for voltage dips, but the motors can probably not handle the voltage difference. It is also less efficient to buck a higher voltage to a lower voltage, so keeping the difference lower is better. We do need to compensate for the possible voltage dips with capacitors and a PSU with a rather high current (probably 10A). I think that a 120W power supply would suffice for this prototype. As an addition we found that the Peltier module usually work on lower voltages like 12V, 5.0V and even 2.2V when they are really small (1cm by 1cm). bucking the voltage from 24 to 12 or lower and still having >3A currents will be very difficult when it comes to sizes of IC’s. using 12V is again beneficial in this case.

Figure 14 Power Management System circuit (simplified)

11.6.7 Trace width
Since high currents will run through the board to some components, we need to create thicker wires other wise the resistance will be too high and the board will heat drastically, possibly leading to traces burning up or degrading over time due to temperature fluctuations.

I used an online calculator to get a overall indication of the track width required. Sadly it seems impossible to create a 5.62 mm trace for every high power net. I decided to go with a trace with that was still possible to route and that roughly resembled the width of the package pins of the power IC use. This may not be the most professional way to test and see if this would work, but it is the only way to go. It later seemed to work perfectly fine using 0.6mm wide traces. It would be a great experiment to check the temperature of the board with a high resolution thermal camera.

I included rounded tracks in the PCB design for two reasons:

1. Rounded tracks serve a functional purpose when signals are being transmitted at above 1Ghz.
2. Rounded tracks give the PCB a visually distinct appearance that can make it stand out. I found it nice to use since the rounded tracks remind me of water.

Overall, the inclusion of rounded tracks in the design serves mostly a aesthetic purpose.

Figure 15 Trace Width Calculator tool

11.6.8 2 VS 4-layer PCB
A PCB (Printed Circuit Board) consists of one or more layers of conductive material, typically copper, separated by insulating layers known as core and prepreg. The number of layers in a PCB can range from one to many, depending on the complexity of the circuit and the required performance.

Here are the main differences between 2-layer and 4-layer PCBs:

1. Number of layers: As the name suggests, a 2-layer PCB has two layers of conductive material, while a 4-layer PCB has four layers.
2. Layout complexity: 2-layer PCBs are typically limited to simple circuits with a small number of components, while 4-layer PCBs can accommodate more complex circuits with a larger number of components.
3. Signal routing: 2-layer PCBs have limited routing options and may require the use of vias (small holes that connect different layers) to route signals between layers. In contrast, 4-layer PCBs have more routing options and typically do not require the use of vias.
4. Performance: 4-layer PCBs can provide better performance compared to 2-layer PCBs, as they offer more routing options and can reduce the effects of crosstalk and noise.

In summary, 2-layer PCBs are suitable for simple circuits with a small number of components, while 4-layer PCBs are better suited for more complex circuits with a larger number of components and higher performance requirements.

In order to minimize the size of the PCB and facilitate its ease of transport and mounting on a Raspberry Pi, we chose to use a 4-layer PCB in the final design. This allows us to easily separate the power planes from the signal wires, which can improve the performance of the circuit. In future designs, it may be beneficial to include a ground plane between the signal and power planes to further improve the performance and EMC (Electromagnetic Compatibility) characteristics of the PCB.

11.6.9 Coil whine
Upon connecting a minor load
(300 mA) to the 5V Raspberry pi
power circuit, I noticed that it generated a high-pitched whine. Upon further investigation, it was determined that the noise was likely emanating from the coil. Upon reviewing the circuit design, I realized that I had omitted the decoupling capacitor from the
output of the LM2596 5.0
regulator. This likely resulted in


the output producing pulses in the kHz range that were audible through the coil.

To resolve this issue, I added an 220 uF capacitor to the output of the regulator. This effectively eliminated the whine and improved the performance of the circuit.

Figure 16 5V power circuit

### 11.7 Backpower protection circuit

The Backpower Protection Circuit (BPC) is designed to protect the Raspberry Pi from damage in the event that a 5V supply is connected to the micro USB port while a 12V supply is simultaneously connected to the barrel jack on the Pi Hat. However, due to a lack of necessary components, this circuit was not tested during the development of the Rastaban project. The BPC can be bypassed by using the solder jumper JP2. To further mitigate the risk of unintended power connections, the housing for the Rastaban project could be designed to cover the micro USB connector.

### 11.8 PCB versions

When fabricating PCBs, it is common to go through multiple iterations before achieving a functional prototype. It is wise to test everything on a breadboard first, but this is not always feasible due to the size of certain components (not breadboard-friendly), the complexity of the circuit, and sometimes the parasitical behavior of the breadboard, which can affect the performance of the prototype. During my internship, I designed three versions of the Rastaban HAT, as well as several simpler PCBs.

11.8.1 PCB V0.1


Figure 17 PCB V0.1

The first version of the PCB was designed to explore multiple options when it comes to driving the motors, led and power the components.

Successes:

- Most of the functions/ elements work
- This layout seems to be a good starting point, maybe some small refinements.
- The mounting holes and dimensions are all correct.

Sadly, the first version of the HAT had more problems than I expected, but I was able to make all the necessary improvements and get a fully functional prototype. I documented all the changes I made, so that I could easily apply them to future PCB’s.

Notes for V0.2 of the Rastaban PCB

Table 5 V0.2 notes

Improvement/note
CHECK THE ORIENTATION OF THE RASPBERRY PI HEADER FOOTPRINT(next time, double, double check)
VCC pin on the drv8838 driver must be connected to 3.3V or 5.0V for it to work.
Try to draw high power traces away from signal traces (move connectors?)
For the 2209 we could use UART port, so we can control clock, micro stepping etc., set parameters, delays, coolstepping, etc.
Buy the right parts 10uf 50V not 10uf 10V
FB1 will not work (made for 150mah), change for different inductor.
Order a lot of Phoenix ptsm connectors (both receptacle and plug)
Remove or find smd variants for fuses (remove some fuses/change values?)
Bypass backpower protection circuit (jumper)
Raspberry pi has decoupling capacitors (caps). Remove caps that are not necessary. Leave c11 and c8.
C5 should be 22uf.
Raspberry pi has build in esd for gpio. Raspberry pi is connected to ground via power connector. Leave ESD footprints, but do not solder them.
Simplify (or maybe even remove) raspberry pi power circuit.
Change inductor for rt7272A boost/buck circuit. Chip gets HOT, possibly switch to buck boost converter or worse case: external PSU for RPI (micro-USB)?
Use a 40 pin FEMALE header on the pcb, not male
Make the schematic more readable. Do not run wires through each other.
Fix u7 (footprint is wrong, partly flipped)
Flat cable for 40 pin to 40 pin connection for easier, safer? For testing purposes. Better diode polarity indication on silkscreen.
J12 silkscreen error: ic and mosfet are flipped

Possibly add pinout (names) to bottom of HAT
ENABLE focus must be using a hierarchal flag! Now it’s global, it’s not consistent.
All stepper motors work fine with 12V, they have more than enough torque even while using 16bit micro stepping. Remove the 24V buck boost converter.
Peltier module has not been evaluated (0.2 sense resistor not received)
Micled IC not tested (ic BCR420UW6-7 not received).
I2c hat functionality (special eeprom chip) not tested.
5.0V for mic led not evaluated. 3.3V from u2 (tlv1117-33) works fine. ESD protection not evaluated.

Maybe use the xl6009 for the raspberry pi and 5V line (4A is possibly more stable than the 3A) or copy a known design (df robot?) (https://www.tinytronics.nl/shop/en/power/voltage-converters/buck-(step-down)-converters/dfrobot-dc-dc-buck-converter-7-24v-to-5v-4a)
Remove some test points to make pcb smaller and routing easier?
I2C NOT working probably due to ESD protection ic. Remove the ic, it’s expensive and time consuming. Use diode alternative, which is optional:

Figure 18 ESD TVS diode option

Small discussion with Jeroen:

- Is a sense resistor a special type of resistor -> figure this out.
- Maybe 5 1ohm resistors in parallel work as an alternative for this sense resistor -> try this to find out if this is something to continue.
- Get current h-bridge working or search for alternative (make your own h-bridge with mosfets maybe, higher currents?)
- Try to fix the power circuit to gain knowledge on the subject.
- Remember: 1 small value cap for low frequency, 1 larger nF cap for higher frequencies.
- Drv8838 keeps turning somehow after disabling it.

Conclusions on process:

- Do not reflow large capacitors. Do it by hand after the small parts have been soldered.
- 230 degrees Celsius is usually hot enough to melt the solder paste.
- Stencils for small footprints diy soldering, otherwise solder connections will fail.
- Always three double check the most important things (footprints).
- Do some life testing so create mockups for PCBs to test fit (also for Industrial designers).
- Check solder connections! Visual inspection! A mosfet with only 2 pins soldered instead of all three does not work.
- Don’t unplug things while they are powered on (hot plug/swap), plug things or measure things while the system is powered.

11.8.1.1 Current usage
I tested what the current usage of the components. Some components could not be tested and have been estimated.

Table 6 Current usage

Component type | Name | Current (A) usage tot.
LED | Microscope led | 0.077
FAN | Cooling FAN | 0.150
HEATER | Power Resistor (10w) | 1.180
Cooler/heater | Peltier | ? 0-3.6
PGPIO | X | 0-6
PGPIO | X | 0-6
Stepper motor (small) | Focus stepper motors | 0.5 (3 motors)
Stepper motor (large) | Primary stepper motor | 1.7
Stepper motor (medium) | Secondary stepper motor | 1.5

11.8.2 PCB V0.2


Figure 19 PCB V0.2

Successes:

- All functions/elements are working now, this version could be used for fluid testing purposes.
- This version is smaller than it’s predecessor L9,9CM; W9,9CM -> L8,4CM; W8,4CM.
- This version is capable of powering the raspberry pi through the GPIO header. External power for the raspberry pi Is no longer necessary.

Notes for V0.3 of the Rastaban PCB

Table 7 V0.3 notes

# | Improvement | Finished

1 | Figure out which hardware pins to use for what components led/focus motor (drv8838) | NO
2 | TMC 2209 uses different ms1 ms2 configuration for micro stepping than the tmc 2208! Keep this in mind. | DONE, modern design uses TMC2209 design config
3 | Remove tmc2208 from design, focus on 2209 | DONE, no more tmc2208.
4 | Use UART on 2209 and remove step/dir enable interface. | DONE, UART is only control way now

5 | Use appropriate resistors for UART control on 2209 (resistance should decrease with increase in drivers). | DONE
6 | Connect diag pin of 2209 for stall (stuck motor) indication for rpi? | NO
7 | Checkout the problems with diag pin on tmc2209 (see pdf in datasheets) | NOT CHECKED
8 | Change L1 footprint | Enlarged and changed to bourns square size
9 | Copper zone for L1 | Copper ground zone added under L1 for MRI protection
10 | Maybe move the camera connector to the left | YES, DONE
11 | Corners in the hat header silkscreen. | Already satisfied in previous version
12 | Raspberry pi power circuit coil whine should be resolved. | Solved, new values added to schematic
13 | Footprints for all power circuit components should be enlarged/checked | Checked, DONE
14 | Add logo v0.2 | DONE

11.8.3 PCB V0.3


Figure 20 PCB V0.3

# | Improvement/note | Implemented/finished

1 | Make the H-bridge compatible with different Peltier module sizes (different voltages)
2 | Possibly breakout more GPIO pins
3 | Watch out for PEO connector on RPI (keep out zone possibly) R2 is now touching the PEO connector.
4 | Heater and microscopeled are behind the USB port of the pi, this is not an option. Next time load in raspberry pi 3D model to catch this issue beforehand. Move connectors or use vertical connectors (easier). For now it is possible to move the hat a bit more up using a taller header or an extender possibly.
5 | Write insertion method for module like the drv8838 and the tmc2209 driver boards (to avoid reversed polarity)
6 | The I2c port should be vertical one as well to keep this small profile board.
7 | It is possible to apply D4 and D1 footprints for D7 and D6 (smaller footprints)
8 | CPU heatsink cannot be placed because of components on bottom side of PCB

Successes:

- All functions/elements are still working.
- This version is smaller than its predecessor L8,4CM; W8,4CM -> L6.8CM; W6.5CM.
- Some footprints changed/enlarged.
- Removed step/dir connections and now using UART on TMC2209 driver.
- Added copper ground zone underneath L1 for MRI protection.
- Refined dimensions for camera cable hole.
- Newly created Rastaban logo added.

Notes for V0.4 of the Rastaban PCB

Table 8 V0.4 notes

For final reference I placed the three PCB designs for Rastaban side by side to accentuate the size reduction and overall component placement improvement over the versions.


Figure 21 PCB V0.1-V0.3

9 | Anode cathode of Diodes may be misleading. The “C” is not always the way the diode should be pointed to (D5, D3)
10 | Remove Resistor R5 and R4. They are not necessary. One 1K resistor works for UART. The silkscreen can be removed as well.
11 | Make sure all stepper motor outputs are wired the same from driver to the connector output. Some are switched up, this could be a problem.
12 | Keep Step and Dir on all drivers, there are enough GPIO pins left.
13 | VIO appears to not be required on the tmc2209 when VM is connected. Remove 3.3V from VIO

### 11.9 Focusing the lens

When imaging small objects through a lens, it is crucial to use a high-quality lens with sufficient magnification to clearly resolve the details of the objects. The working distance of the lens, or the distance between the lens and the object, should also be considered as it affects the ability to achieve focus.

There are several ways to adjust the distance between the lens and the object. One method is to use a voice coil, which works by magnetizing the coil to move it slightly closer or farther from the object, similar to the principle of a speaker coil. The Rastaban project can use a voice coil setup controlled by, for example, a DRV8838 driver. Another method is to use stepper motors to move the lens up and down. The design created by Jeroen uses three stepper motors in parallel for this purpose and will be controlled using TMC2209 drivers. It may be necessary to limit the current provided by the TMC2209 drivers through the UART settings in order to protect the small and vulnerable motors.

## 12 Software

The software written for the Rastaban (HAT) has been made in the Python language. This language is chosen because it is widely used in the Raspberry pi community and it gives us the ability to use the PYQT GUI library. Other reasons are maybe for the ease of use and the reason that it is not compiled but interpreted code, which makes it faster for prototyping purposes. Most of the code is written in an object oriented style. I find this code looking cleaner and more maintainable than the regular coding style I know see Figure 22 Example of object oriented written code (PWM) for reference.

### 12.1 Components

To give a short overview of the code, I will describe all
components in short. I will not go into detail on the
functions of the components, since the Doxygen file is much more conclusive and is fluid in it’s versions, while this document may become obsolete sooner or later. Component list:
- Microscope LED
- Stepper motor driver
- PowerGPIO
- Cooling Fan
- Peltier Module
- Voice coil
- PIGPIO
- Init (PIGPIO)

12.1.1 Microscope LED

The CN5711 is utilized to control the microscope led. The device is driven by a Hardware PWM signal send by the raspberry pi. The code can control the LED’s brightness, switching frequency, duty cycle and on/off state.

12.1.2 TMC2209 Stepper motor driver
We can use both step/dir commands to control the motor drivers for “legacy” stepper motor control, as we can use UART, the more modern way to control and set the stepper motor drivers. V0.3 of the Rastaban PCB only uses UART to control the stepper motor drivers.

The TMC2209 stepper motor driver can be controlled through its UART (Universal Asynchronous Receiver/Transmitter) interface. To use this interface, a UART-to-serial converter (such as a USB-to-serial adapter) is used to connect the TMC2209 to a microcontroller or computer. The microcontroller or computer can then send commands to the TMC2209 using a specific protocol, and receive status information from the TMC2209 in return. This allows for real-time customization and monitoring of the driver's behavior. We use the following library to control the drivers via UART: https://github.com/Chr157i4n/TMC2209_Raspberry_Pi

12.1.3 PowerGPIO, Cooling Fan, Heating resistor
The power GPIO pins are driven using software PWM as well as the Cooling Fan and the Heating resistor. This code drives the mosfet that is responsible for switching the load.

The Peltier driver is controlled using two software PWM signals. Sending to IN1 and IN2 will control the output of the H-bridge.

Figure 22 Example of object oriented written code (PWM)

12.1.4 Voicecoil
The Voice coil code controls the voice coil for focusing the lens. The code was designed for the DRV8838 motor driver.

12.1.5 Pigpio
Pigpiod or pigpio is a utility which launches the pigpio library as a daemon.
Once launched the pigpio library runs in the background accepting commands from the pipe and socket interfaces.
The pigpiod utility requires sudo privileges to launch the library but thereafter the pipe and socket
commands may be issued by normal users. There are several reasons why we might choose to use the pigpio library:
- It provides a simple interface for controlling the GPIO pins: The pigpio library provides functions for setting the direction and level of individual pins, as well as for configuring PWM and detecting changes on the pins.
- It is lightweight and efficient: The pigpio daemon runs in the background and communicates with the pigpio library via a socket, which means that it has minimal overhead and does not require any additional libraries to be installed.
- It is flexible: The pigpio library allows users to control the GPIO pins from multiple programming languages, including C, Python, and Perl.
- It is well documented: The pigpio library comes with detailed documentation that explains how to use the library and troubleshoot any issues that may arise.

Overall, the pigpio library is a popular choice for controlling the GPIO pins on a Raspberry Pi because it is easy to use, efficient, flexible, and well documented. That is the reason why we choose to implement it in our Rastaban code.

12.1.6 Init function (PIGPIO daemon)
I created an init function for the Raspberry Pi to address unexpected behavior of the GPIO pins when using the pigpio daemon. Some pins were unable to go LOW or did not properly utilize PWM. If you wish to run Rastaban code that utilizes PIGPIO functions, you can run the Init function once to start the pigpio daemon. The function will indicate whether the daemon was already running and display its process ID. By restart or after a shutdown of the raspberry pi, the daemon would be stopped. It is possible to run this code on start-up of the RPI, but it may be better to run this code when the final Rastaban code has been created.

### 12.2 Doxygen

I chose to use Doxygen because for the following reasons:

1. Improved code readability: Doxygen can help you create clear and concise documentation for your code, which can make it easier for other developers to understand and use your code.
2. Enhanced collaboration: Doxygen can help you document your code in a way that is more accessible to other developers, which can facilitate collaboration and make it easier for others to contribute to your project.
3. Increased code maintainability: By documenting your code with Doxygen, you can make it easier for other developers to understand and maintain your code over time. This can be particularly important for larger projects with many contributors.

4. Professional-quality documentation: Doxygen can generate professional-quality documentation in a variety of formats, including HTML, LaTeX, and PDF, making it easy to create high-quality documentation for your project.

Overall, using Doxygen can help create more readable, maintainable, and collaborative software projects by providing comprehensive documentation for my code. Therefore, all the code for the Rastaban has been processed using Doxygen and is primarily documented in this way.

### 12.3 GUI

It was planned to control the Rastaban project via an GUI. This could make it easier to control the setup for the end user. As said before the user may be a student, teacher or possibly a researcher who most likely has not a very wide understanding of the Rastaban code or product as a whole. This GUI should make it easy for them to interact with the device. Below is shown the function of the GUI in the system.

Figure 23 Application of GUI in the system

I created a crude window sketch for controlling the Rastaban project.


Figure 24 Windows sketch GUI

12.3.1 GUI design
After having a general idea of how I wanted my GUI to function, I searched for possible input methods to put in my GUI. There are many options, sliders, dials etc. I ultimately decided to go with, in my opinion, easiest and safest option, by using only buttons and arrows that need to be clicked or scrolled on. I think that using a dial can be useful for an led for example for quick testing, but not for high power components like the Peltier or heating resistor. I think it would be dangerous to accidentally turn a dial to these high power components and a dial or slider doesn’t seem to be precise enough compared to setting numbers.

12.3.2 Final design sketch
Ultimately I think that functionality and safety in the GUI are of highest priority. That’s why in my final design sketch I made buttons to toggle enable/disable to specific blocks of control or the whole control window.

Too have full and precise control over the components, numbers can be set manually in the text boxes. The numbers can be changed by typing them in, scrolling on the box or clicking on the arrow, up/down.

This window/GUI may be build upon to give it functionality and add signals and slots to integrate it with the main Rastaban code.


Figure 25 GUI widget options in one window


Figure 26 Final design sketch GUI

## 13 Results

Having spend hours working on this project working on both refining the hardware and software of the Rastaban prototype. I have successfully created the first fully functional prototype.

### 13.1 Hardware

The Rastaban HAT prototype has the following functionality (in short)

- Can control 3 stepper motors.
- Has two power GPIO pins (providing 12V 6A each)
- Can control an LED using a constant current IC.
- Can control the voice coil using the drv8838 driver.
- Can control a 12V 3.6A Peltier module using the DRV8870DDA H-bridge.
- Can control power to a heating resistor.
- Can control a fan for removing heat from the Peltier module heatsink.
- Has optional EEPROM ID configuration on PCB.
- Has a backpower protection circuit, fuses and ESD + EMC precautions.
- Has GPIO breakout pins for external control.
- Has power breakout pins for external power.
- It’s HAT formfactor has been achieved.

Figure 27 All PCB's and final result on foreground

### 13.2 Software

The software control the Rastaban HAT is written in python and in the object oriented style. With the software you have full control of the outputs of the Rastaban HAT. V0.3 uses UART to control its stepper motors but for legacy control of V0.1 and V0.2 steppermotors.py is still present.

In short, the software functions:

- Fan: fan control using PWM.
- Heatingresistor: control power to resistor using PWM.
- Init: code to initialize and see current process id of the PIGPIO daemon.
- Microscopeled: control the microscope LED using hardware PWM.
- Peltier: control the H-bridge that controls power to the Peltier element.
- Powergpio: control power output on powergpio using PWM.
- Pwm: the pwm class.
- RastabanV0.3Demo: this code has not been realized yet, but could be used for demonstration purposes. All code has a build in test function (unit test).
- Steppermotors: legacy stepper motor control code using step/dir and enable pins. This is for backwards compatibility with older PCB versions.
- UARTsteppermotor: the new stepper motor control method that is used in V0.3 of the Rastaban PCB. This code gives is a encapsulated version of the TMC_2209_UART code. It is created to make testing easier in some situations.
- Voice coil: controls the voice coil by controlling the DRV8838
driver.

Note: Figure 24 Windows sketch GUI that I created can be used as an starting point to connect this code to.

Figure 28 All scripts and supporting code for the Rastaban HAT

## 14 Conclusion and recommendations

The hardware and software that I created is suitable for most of the WQM purposes and for the DNA research in the future. However there are many improvements that could be made, especially when it comes to the software. The GUI for example could be extended on and integrated into the control code of the Rastaban. There is also no fault detection in the software. Sometimes this is due to hardware limitations (no flags present), but often there could be error codes like: “pin not found, is everything connected correctly?” for example.

The hardware is functional and the motor driver modules are easily replaceable if something brakes. However it would be far cheaper to place the components directly on the PCB. There should be flyback protection added in that case (for accidental motor BackEMF). By integrating everything on the main PCB, production time and costs would be greatly reduced. It is also not always certain which driver module version you receive, which could sometimes lead to unpredictable behavior. Another improvement could be to place the connectors vertically, but this depends on the preference of the user. For more notes see Table 8 V0.4 notes.

## 15 Appendix A: ChatGPT

### 15.1 ChatGPT usage in this report

This year a new AI was introduced: ChatGPT. I will let it introduce itself:


Figure 29 ChatGPT introduction

It however is very capable of doing a wide variety of things. It can give you code snippets, rewrite text, rewrite code etc. It is also capable of creating poems with the input of your choice. Or as it says itself.

I have used ChatGPT for the following:

1. Improve writing style: the AI rewrites sentences to sound more fluid, more efficient, conclusive, and shorter.
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

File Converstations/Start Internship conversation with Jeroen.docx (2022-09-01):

# First conversation with Jeroen on my internship

I will be working with a biosensor. The project will be made in cooperation with the WUR (Wageningen Universiteit).

We are creating a water quality monitor (fluid analyser?)

Crude Requirements we set up

SMART Functional specifications
# | MoS CoW | Description

F1 | M | Controlling and collecting data from the biosensor setup
F1.1 | M | Particle detection
F1.2 | M | Temperature control
F1.3 | M | Fluid manipulation
F1.4 | M | decontamination of the reaction chamber

Ancillary activities, along/besides my main project:
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

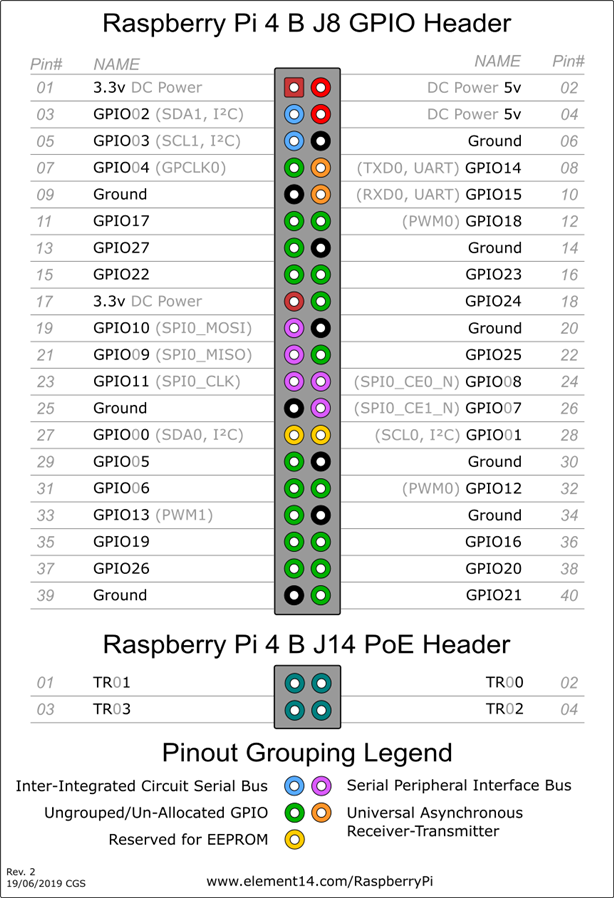
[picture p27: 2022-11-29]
Hardware/PI4_GPIO_HEADER.png

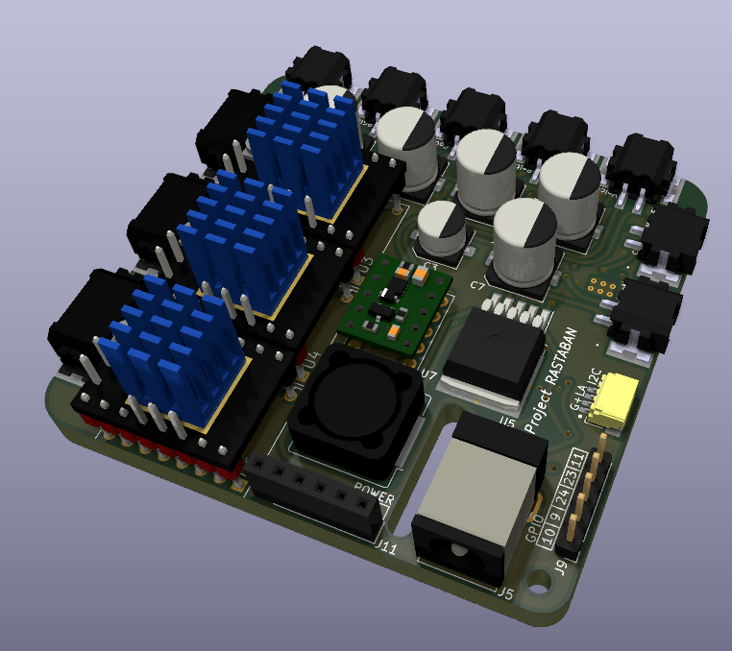
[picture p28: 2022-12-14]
Hardware/Finalized 3D design Rastaban Hat V0.3 Front .png

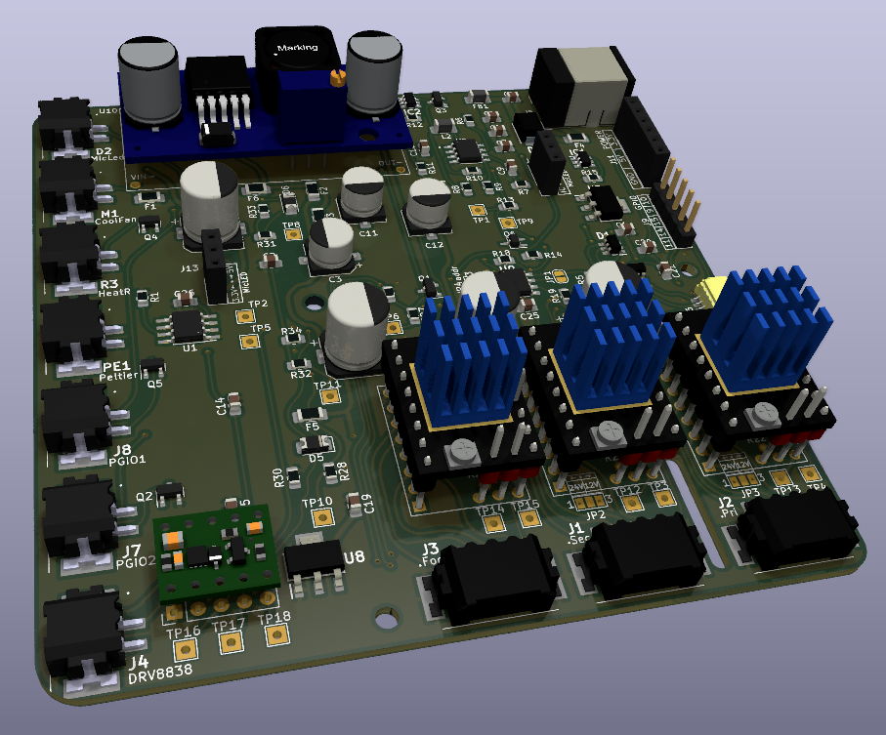
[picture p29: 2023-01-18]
Hardware/V0.1.png

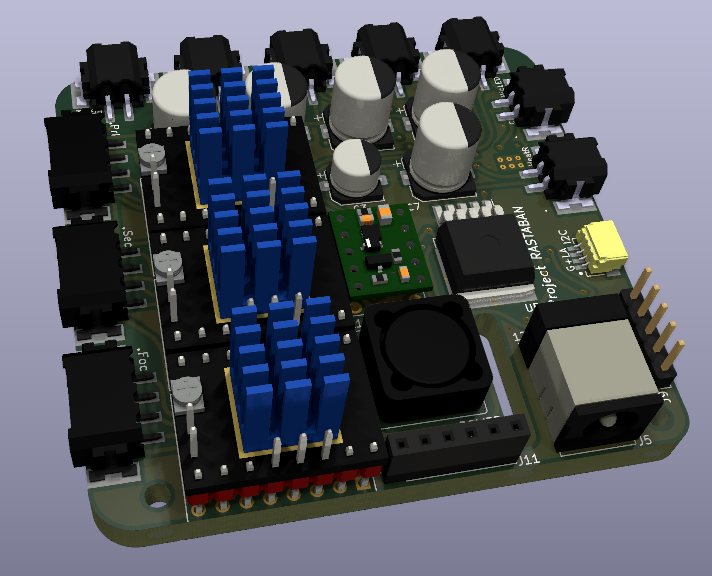
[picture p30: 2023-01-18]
Hardware/V0.3.png

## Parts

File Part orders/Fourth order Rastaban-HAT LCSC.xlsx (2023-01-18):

Collated Components: |  |  | ORDER THE GREEN PARTS
Item | Qty | Reference(s) | Value | LibPart | Footprint | LCSC | Mouser Part Number | FABNR
1 | 4 | C1, C5, C6, C19 | 10uF 50V | Device:C | Capacitor_SMD:C_0805_2012Metric_Pad1.18x1.45mm_HandSolder | C15850
2 | 7 | C2, C14, C15, C22, C23, C24, C26 | 100nF 50V | Device:C | Capacitor_SMD:C_0805_2012Metric_Pad1.18x1.45mm_HandSolder | C476766
3 | 1 | C3 | 47uF 50V | Device:C | Capacitor_SMD:CP_Elec_6.3x5.4 | C72522
4 | 1 | C7 | 22uF 25V | Device:C_Polarized | Capacitor_SMD:C_0805_2012Metric_Pad1.18x1.45mm_HandSolder | C5155340
5 | 3 | C16, C17, C18 | 100uF 50V | Device:C | Capacitor_SMD:CP_Elec_8x10 | C445063
6 | 1 | C25,C13 | 100nF 50V | Device:C_Small | Capacitor_SMD:C_0805_2012Metric_Pad1.18x1.45mm_HandSolder | C476766
7 | 2 | D1, D4 | ESD7351HT1G | SamacSys_Parts:ESD7351HT1G | SamacSys_Parts:SOD2512X110N | C5210965 | 863-ESD7351HT1G
8 | 1 | D2 | OVLEW1CB9 | SparkFun-LED:LED5MM | SamacSys_Parts:1808190 |  | 828-OVLEW1CB9
9 | 1 | D3 | SMBJ26A | SamacSys_Parts:SMBJ26A | SamacSys_Parts:DIOM5436X261N | C10216 | 652-SMBJ26A
10 | 1 | D7 | SS310 | Device:D_Schottky | SamacSys_Parts:SOD2512X110N | C15874
11 | 1 | F1 | 8A | Device:Fuse | Fuse:Fuse_1206_3216Metric_Pad1.42x1.75mm_HandSolder | C136353
12 | 2 | F2, F3 | 5A | Device:Fuse | Fuse:Fuse_1206_3216Metric_Pad1.42x1.75mm_HandSolder | C355689
13 | 1 | F4 | 4A | Device:Fuse | Fuse:Fuse_1206_3216Metric_Pad1.42x1.75mm_HandSolder | C355687
14 | 1 | FB1 | 150uH | Device:FerriteBead | Inductor_SMD:L_1206_3216Metric_Pad1.22x1.90mm_HandSolder | C250237
15 | 1 | IC1 | BCR420UW6-7 | SamacSys_Parts:BCR420UW6-7 | SamacSys_Parts:SOT95P280X145-6N | C194381 | 621-BCR420UW6-7
16 | 1 | IC2 | BCM53DS | SamacSys_Parts:DMMT5401-7-F | SamacSys_Parts:SOT95P280X145-6N |  | 771-BCM53DSF
17 | 3 | J1, J2, J3 | 1778780 | :1778780_1 | SamacSys_Parts:1778780 | C5173835 | 651-1778780
18 | 3 | J4, J7, J8 | Screw_Terminal_01x02 | Connector:Screw_Terminal_01x02 | SamacSys_Parts:1808190 |  | 651-1808190
19 | 1 | J5 | Jack-DC 12V+ | Connector:Jack-DC | Connector_BarrelJack:BarrelJack_Wuerth_6941xx301002 |  | 992-CON-SOCJ-2155
20 | 1 | J6 | SM04B-SRSS-TB(LF)(SN) | SM04B-SRSS-TB_LF__SN_:SM04B-SRSS-TB(LF)(SN) | SnapEDA Library:JST_SM04B-SRSS-TB(LF)(SN) | C160404
21 | 1 | J9 | Conn_01x05_Male | Connector:Conn_01x05_Male | Connector_PinHeader_2.54mm:PinHeader_1x05_P2.54mm_Vertical | x
22 | 1 | J10 | GPIO | Connector_Generic:Conn_02x20_Odd_Even | Connector_PinHeader_2.54mm:PinHeader_2x20_P2.54mm_Vertical_SMD
23 | 1 | J11 | Conn_01x06_Male | Connector:Conn_01x06_Male | Connector_PinSocket_2.54mm:PinSocket_1x06_P2.54mm_Vertical | x
24 | 1 | JP1 | ID_WP | Jumper:SolderJumper_2_Open | Jumper:SolderJumper-2_P1.3mm_Open_RoundedPad1.0x1.5mm | x
25 | 1 | JP2 | Jumper_2_Open | Jumper:Jumper_2_Open | Jumper:SolderJumper-2_P1.3mm_Open_RoundedPad1.0x1.5mm | x
26 | 3 | JP3, JP4, JP5 | Jumper_3_Open | Jumper:Jumper_3_Open | Jumper:SolderJumper-3_P1.3mm_Open_Pad1.0x1.5mm_NumberLabels | x
27 | 1 | L1 | 68uH | Device:L | Inductor_SMD:L_Bourns-SRU8028_8.0x8.0mm | C82571
28 | 1 | M1 | Fan | Motor:Fan | SamacSys_Parts:1808190 | x
29 | 1 | PE1 | PeltierElement | Device:PeltierElement | SamacSys_Parts:1808190 | x
30 | 4 | Q1, Q2, Q4, Q5 | PMV15ENE | Transistor_FET:2N7002K | Package_TO_SOT_SMD:SOT-23 | C3647053
31 | 1 | Q3 | DMG2305UX-7 | SamacSys_Parts:DMG2305UX-7 | Package_TO_SOT_SMD:SOT-23 | C2940629 | 621-DMG2305UX-7
32 | 1 | Q6 | 2N70002HWX | Transistor_FET:DMG1012T | Package_TO_SOT_SMD:SOT-323_SC-70_Handsoldering | C3647053
33 | 1 | R1 | 0.2 | Device:R | Resistor_SMD:R_0805_2012Metric_Pad1.20x1.40mm_HandSolder |  | 71-WSL1206-0.2/R
34 | 1 | R2 | 680 | Device:R | Resistor_SMD:R_0603_1608Metric_Pad0.98x0.95mm_HandSolder | C17798
35 | 1 | R3 | 10W resistor | SparkFun-Resistors:1.20KOHM-0603-1_10W-1% | SamacSys_Parts:1808190 | x
36 | 1 | R6 | 220 | Device:R | Resistor_SMD:R_0603_1608Metric_Pad0.98x0.95mm_HandSolder | C17557
37 | 6 | R11, R13, R29, R30, R33, R34 | 10k | Device:R | Resistor_SMD:R_0805_2012Metric_Pad1.20x1.40mm_HandSolder | C5140188
38 | 1 | R12 | 47K | Device:R | Resistor_SMD:R_0805_2012Metric_Pad1.20x1.40mm_HandSolder | C102018
39 | 5 | R14, R27, R28, R31, R32 | 1k | Device:R | Resistor_SMD:R_0805_2012Metric_Pad1.20x1.40mm_HandSolder | C17414
40 | 1 | R15 | 30 | Device:R | Resistor_SMD:R_0805_2012Metric_Pad1.20x1.40mm_HandSolder | C3016603
41 | 2 | R18, R19 | 3.9k | Device:R_Small | Resistor_SMD:R_0805_2012Metric_Pad1.20x1.40mm_HandSolder | C2907252
42 | 6 | R20, R21, R22, R23, R24, R25 | 22k | Device:R | Resistor_SMD:R_0805_2012Metric_Pad1.20x1.40mm_HandSolder | C114565
43 | 1 | U1 | DRV8870DDA | Driver_Motor:DRV8870DDA | Package_SO:Texas_HTSOP-8-1EP_3.9x4.9mm_P1.27mm_EP2.95x4.9mm_Mask2.4x3.1mm_ThermalVias | x
44 | 2 | U2, U8 | TLV1117-33 | Regulator_Linear:TLV1117-33 | SamacSys_Parts:SOT230P700X180-4N | C37359
45 | 3 | U3, U4, U6 | TMC2208_Carrier | :TMC2208_SILENTSTEPSTICK_1 | SnapEDA Library:MODULE_TMC2208_SILENTSTEPSTICK | x
46 | 1 | U5 | LM2596S-5.0 | Regulator_Switching:LM2596S | Package_TO_SOT_SMD:TO-263-5_TabPin3 | C347421
47 | 1 | U7 | DRV8838 POLOLU | Driver_Motor:DRV8838 POLOLU | Module:DRV8838 POLOLU | x
48 | 1 | U9 | CAT24C256 | Memory_EEPROM:CAT24C256 | SamacSys_Parts:SOIC127P600X175-8N | x
49 | 20 |  |  | PC 2 pin ptsm MALE |  |  | 651-1709457 | 1709457
50 | 20 |  |  | PC 4 pin ptsm MALE |  |  | 651-1709460 | 1709460

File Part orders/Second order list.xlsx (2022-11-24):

Bestelformulier
Let op: alleen volledig ingevulde formulieren worden in behandeling genomen.
Je bestellijst stuur je naar: | tom.franssen@han.nl | en een CC naar je docent
Je ontvangt op het door jou aangegeven email-adres een bericht wanneer je bestelling afgehaald kan worden
Naam | Artikel | Artikelnummer | Aantal | Leverancier | Prijs/st (excl BTW) | Totale kosten (excl BTW)
Jeroen Veen | p82b96td,118 | P82B96TD,118 | 4 | farnell | 4.32 | 17.28
Casper Tak | cat24c256hu4igt3 | CAT24C256HU4IGT3 | 1 | farnell | 0.845 | 0.845
 | IRL540SPBF | IRL540SPBF | 10 | farnell | 3.84 | 38.4
 | DRV8870DDA | drv8870dda | 5 | texas instruments | 1.842 | 9.21
 | TMC2208 Motor Driver Module | 001585 | 2 | TINYTRONICS | 6.61 | 13.22
 |  |  |  |  |  | 0
 |  |  |  |  |  | 0
 |  |  |  |  |  | 0
 |  |  |  |  |  | 0
 |  |  |  |  |  | 0
 |  |  |  |  |  | 0
 |  |  |  |  |  | 0
 |  |  |  |  |  | 0
 |  |  |  |  |  | 0
Alieexpress componenten dubbel bestellen (ivm levertijden?)
SMD componenten (1206) alvast bestellen?
tmc2208 via alie bijbestellen alvast? (sinds het de primaire driver is)

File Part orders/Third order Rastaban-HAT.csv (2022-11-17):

Source: | C:\Users\crtak\HAN\Jeroen Veen - Effluent\07 Studentprojects\Casper Tak\Hardware\Rastaban-HAT\Rastaban-HAT\Rastaban-HAT.kicad_sch
Date: | 13/10/2022 11:12
Tool: | Eeschema (6.0.6)
Generator: | C:\Program Files\KiCad\6.0\bin\scripting\plugins/bom_csv_grouped_by_value.py
Component Count: | 125
 |  |  | MISTAKES IN SOME NAMES MOUSER
Collated Components:
Item | Qty | Reference(s) | Value | LibPart | Footprint | LCSC | Mouser | TinyTronics | Vanallesenmeer
1 | 5 | C1, C5, C6, C7, C19 | 10uF 50V | Device:C | Capacitor_SMD:C_0805_2012Metric_Pad1.18x1.45mm_HandSolder | C17024
2 | 10 | C2, C8, C10, C13, C14, C15, C22, C23, C24, C26 | 100nF 50V | Device:C | Capacitor_SMD:C_0805_2012Metric_Pad1.18x1.45mm_HandSolder | C531179
3 | 1 | C3 | 47uF 50V | Device:C | Capacitor_SMD:CP_Elec_6.3x5.4 | C72522
4 | 4 | C4, C16, C17, C18 | 100uF 50V | Device:C | Capacitor_SMD:CP_Elec_8x10 | C445063
5 | 1 | C9 | 2.7nF 50V | Device:C | Capacitor_SMD:C_0805_2012Metric_Pad1.18x1.45mm_HandSolder | C376966
6 | 2 | C11, C12 | 22uF 50V | Device:C | Capacitor_SMD:CP_Elec_6.3x5.8 | C128458
7 | 3 | C20, C21, C25 | 100nF 50V | Device:C_Small | Capacitor_SMD:C_0805_2012Metric_Pad1.18x1.45mm_HandSolder | C531179
8 | 2 | D1, D4 | D5V0P4UR6SO-7 | :D5V0P4UR6SO-7_1 | SamacSys_Parts:SOT95P285X140-6N | C531179 | 621-D5V0P4UR6SO-7
9 | 1 | D2 | OVLEW1CB9 | SparkFun-LED:LED5MM | SamacSys_Parts:1808190 |  | 828-OVLEW1CB9
10 | 1 | D3 | SMBJ26A | SamacSys_Parts:SMBJ26A | SamacSys_Parts:DIOM5436X261N | C10216
11 | 2 | D5, D6 | DIODE-1N4148 | SparkFun-DiscreteSemi:DIODE-1N4148 | Diode_SMD:D_1206_3216Metric_Pad1.42x1.75mm_HandSolder | C2128 | 512-1N4148WS
12 | 1 | F1 | 0.5A | Device:Fuse | Fuse:Fuse_1206_3216Metric_Pad1.42x1.75mm_HandSolder | C140536
13 | 1 | F2 | 4A | Device:Fuse | Fuse:Fuse_1206_3216Metric_Pad1.42x1.75mm_HandSolder | C178929
14 | 3 | F3, F5, F6 | 5A | Device:Fuse | Fuse:Fuse_1206_3216Metric_Pad1.42x1.75mm_HandSolder | C182986
15 | 1 | F4 | 10A | Device:Fuse | Fuse:Fuse_1206_3216Metric_Pad1.42x1.75mm_HandSolder | C140473
16 | 1 | FB1 | 150uH | Device:FerriteBead | Inductor_SMD:L_1206_3216Metric_Pad1.22x1.90mm_HandSolder | C250237
17 | 1 | IC1 | BCR420UW6-7 | SamacSys_Parts:BCR420UW6-7 | SamacSys_Parts:SOT95P280X145-6N |  | 621-BCR420UW6-7
18 | 1 | IC2 | BCM53DS | SamacSys_Parts:DMMT5401-7-F | SamacSys_Parts:SOT95P285X140-6N |  | 771-BCM53DSF
19 | 3 | J1, J2, J3 | 1778780 | :1778780_1 | SamacSys_Parts:1778780 | C5173835
20 | 3 | J4, J7, J8 | Screw_Terminal_01x02 | Connector:Screw_Terminal_01x02 | SamacSys_Parts:1808190 |  | 651-1808190
21 | 1 | J5 | Jack-DC 12V+ | Connector:Jack-DC | Connector_BarrelJack:BarrelJack_Wuerth_6941xx301002 |  | 710-694106301002
22 | 1 | J6 | SM04B-SRSS-TB(LF)(SN) | SM04B-SRSS-TB_LF__SN_:SM04B-SRSS-TB(LF)(SN) | SnapEDA Library:JST_SM04B-SRSS-TB(LF)(SN) | C160404
23 | 1 | J9 | Conn_01x05_Male | Connector:Conn_01x05_Male | Connector_PinHeader_2.54mm:PinHeader_1x05_P2.54mm_Vertical | x | x
24 | 1 | J10 | GPIO | Connector_Generic:Conn_02x20_Odd_Even | Connector_PinHeader_2.54mm:PinHeader_2x20_P2.54mm_Vertical_SMD |  | 485-2187
25 | 1 | J11 | Conn_01x06_Male | Connector:Conn_01x06_Male | Connector_PinSocket_2.54mm:PinSocket_1x06_P2.54mm_Vertical | x | x
26 | 1 | J12 | Conn_01x03_Male | Connector:Conn_01x03_Male | Connector_PinSocket_2.54mm:PinSocket_1x03_P2.54mm_Vertical | x | x
27 | 1 | JP1 | ID_WP | Jumper:SolderJumper_2_Open | Jumper:SolderJumper-2_P1.3mm_Open_RoundedPad1.0x1.5mm | x | x
28 | 3 | JP2, JP3, JP4 | Jumper_3_Open | Jumper:Jumper_3_Open | Jumper:SolderJumper-3_P1.3mm_Open_Pad1.0x1.5mm_NumberLabels | x | x
29 | 1 | L2 | 15uH | Device:L_Iron | Inductor_SMD:L_1206_3216Metric_Pad1.22x1.90mm_HandSolder | CY54-15UH
30 | 1 | M1 | Fan | Motor:Fan | SamacSys_Parts:1808190 |  | 651-1808190
31 | 1 | PE1 | PeltierElement | Device:PeltierElement | SamacSys_Parts:1808190 |  | 651-1808190
32 | 4 | Q1, Q2, Q4, Q5 | PMV15ENE | Transistor_FET:2N7002K | Package_TO_SOT_SMD:SOT-23 |  | 771-PMV15ENER
33 | 1 | Q3 | DMG2305UX-7 | SamacSys_Parts:DMG2305UX-7 | Package_TO_SOT_SMD:SOT-23 | C2940629
34 | 1 | Q6 | 2N70002HWX | Transistor_FET:DMG1012T | Package_TO_SOT_SMD:SOT-323_SC-70_Handsoldering | C3647053 | 771-2N7002HWX
35 | 1 | R1 | 0.2 | Device:R | Resistor_SMD:R_0805_2012Metric_Pad1.20x1.40mm_HandSolder |  | 771-PMV15ENER
36 | 1 | R2 | 0 | Device:R | Resistor_SMD:R_0805_2012Metric_Pad1.20x1.40mm_HandSolder |  | 71-RCWE0805R300FKEA
37 | 1 | R3 | 10W resistor | SparkFun-Resistors:1.20KOHM-0603-1_10W-1% | SamacSys_Parts:1808190 | x | x
38 | 2 | R4, R5 | 10K | Device:R | Resistor_SMD:R_0805_2012Metric_Pad1.20x1.40mm_HandSolder | C5140188
39 | 1 | R6 | 178k | Device:R | Resistor_SMD:R_0805_2012Metric_Pad1.20x1.40mm_HandSolder | C218368
40 | 1 | R7 | 24k | Device:R | Resistor_SMD:R_0805_2012Metric_Pad1.20x1.40mm_HandSolder | C2907246
41 | 8 | R8, R10, R11, R13, R29, R30, R33, R34 | 10k | Device:R | Resistor_SMD:R_0805_2012Metric_Pad1.20x1.40mm_HandSolder | C5140188
42 | 1 | R9 | 1k87 | Device:R | Resistor_SMD:R_0805_2012Metric_Pad1.20x1.40mm_HandSolder |  | 279-CPF0805B1K87E1
43 | 1 | R12 | 47K | Device:R | Resistor_SMD:R_0805_2012Metric_Pad1.20x1.40mm_HandSolder | C102018
44 | 5 | R14, R27, R28, R31, R32 | 1k | Device:R | Resistor_SMD:R_0805_2012Metric_Pad1.20x1.40mm_HandSolder | C17414
45 | 1 | R15 | 30 | Device:R | Resistor_SMD:R_0805_2012Metric_Pad1.20x1.40mm_HandSolder | C3016603 | 71-RCWE0805R300FKEA
46 | 2 | R18, R19 | 3.9k | Device:R_Small | Resistor_SMD:R_0805_2012Metric_Pad1.20x1.40mm_HandSolder | C2907252
47 | 6 | R20, R21, R22, R23, R24, R25 | 22k | Device:R | Resistor_SMD:R_0805_2012Metric_Pad1.20x1.40mm_HandSolder | C114565
48 | 18 | TP1, TP2, TP3, TP4, TP5, TP6, TP7, TP8, TP9, TP10, TP11, TP12, TP13, TP14, TP15, TP16, TP17, TP18 | TestPoint | Connector:TestPoint | TestPoint:TestPoint_THTPad_2.0x2.0mm_Drill1.0mm | x | x
49 | 1 | U1 | DRV8870DDA | Driver_Motor:DRV8870DDA | Package_SO:Texas_HTSOP-8-1EP_3.9x4.9mm_P1.27mm_EP2.95x4.9mm_Mask2.4x3.1mm_ThermalVias |  | 595-DRV8870DDA
50 | 2 | U2, U8 | TLV1117-33 | Regulator_Linear:TLV1117-33 | SamacSys_Parts:SOT230P700X180-4N | C37359
51 | 3 | U3, U4, U6 | TMC2208_Carrier | :TMC2208_SILENTSTEPSTICK_1 | SnapEDA Library:MODULE_TMC2208_SILENTSTEPSTICK |  |  | https://www.tinytronics.nl/shop/nl/mechanica-en-actuatoren/motoraansturingen-en-drivers/stappen-motoraansturingen-en-drivers/tmc2208-motor-driver-module
52 | 1 | U5 | RT7272AGSP | RT7272AGSP:RT7272AGSP | SnapEDA Library:SOIC127P599X175-9N | C3031672
53 | 1 | U7 | DRV8838 POLOLU | Driver_Motor:DRV8838 POLOLU | Module:DRV8838 POLOLU |  |  |  | https://www.vanallesenmeer.nl/DRV8838-Single-Brushed-DC-Motor-Driver-Carrier-Pololu-2990
54 | 1 | U9 | CAT24C256 | Memory_EEPROM:CAT24C256 | SamacSys_Parts:SOIC127P600X175-8N |  | 698-CAT24C256WI-GT3
55 | 1 | U10 | xl6009_module | Battery_Management:xl6009_module | Connector_PinHeader_1.00mm:xl6009 Boost converter |  |  | https://www.tinytronics.nl/shop/nl/power/spanningsconverters/boost-(step-up)-converters/dc-dc-verstelbare-step-up-boost-converter-xl6009-4a
56 | 5 | B1 | CR1220-2 | Battery Mount |  | C70381

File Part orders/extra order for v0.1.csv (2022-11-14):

LCSC Part Number | Manufacture Part Number | Manufacturer | Package | Customer # | Description | RoHS | Order Qty. | Min\Mult Order Qty. | Unit Price | Order Price | Product Link
C2682489 | TCC0805X7R104M500DTS | CCTC | 0805 |  | 50V 100nF ±20% 0805 Multilayer Ceramic Capacitors MLCC - SMD/SMT ROHS | yes | 100 | 100 | 0.0039 | 0.39 | https://assets.lcsc.com/images/lcsc/96x96/20210105_CCTC-TCC0805X7R104M500DTS_C2682489_front.jpg
C4747967 | RST100UF50V012 | KNSCHA | SMD,D8xL10.5mm |  | 100uF 50V ±20% SMD,D8xL10.5mm Aluminum Electrolytic Capacitors - SMD ROHS | yes | 10 | 10 | 0.0667 | 0.67 | https://assets.lcsc.com/images/lcsc/96x96/20220726_KNSCHA-RST100UF50V012_C4747967_front.jpg
C2992614 | XT22UF50V90RV0083 | KNSCHA | SMD,D6.3xL5.4mm |  | 22uF 50V SMD,D6.3xL5.4mm Aluminum Electrolytic Capacitors - SMD ROHS | yes | 20 | 20 | 0.0358 | 0.72 | https://assets.lcsc.com/images/lcsc/96x96/20220628_KNSCHA-XT22UF50V90RV0083_C2992614_front.jpg
C2992613 | XT47UF50V90RV0082 | KNSCHA | SMD,D6.3xL7.7mm |  | 47uF 50V SMD,D6.3xL7.7mm Aluminum Electrolytic Capacitors - SMD ROHS | yes | 10 | 10 | 0.0388 | 0.39 | https://assets.lcsc.com/images/lcsc/96x96/20220628_KNSCHA-XT47UF50V90RV0082_C2992613_front.jpg
C79987 | CAT24C256WI-GT3 | onsemi | SOIC-8_150mil |  | SOIC-8_150mil EEPROM ROHS | yes | 5 | 1 | 0.4964 | 2.48 | https://assets.lcsc.com/images/lcsc/96x96/20190222_onsemi-CAT24C256WI-GT3_C79987_front.jpg
C182451 | 24E1500A | Shenzhen lanson Elec | SMD |  | 50A SMD Ceramic Fuse 5A 58 SMD Fuses ROHS | yes | 10 | 10 | 0.0624 | 0.62 | https://assets.lcsc.com/images/lcsc/96x96/20180914_Shenzhen-lanson-Elec-24E1500A_C182451_front.jpg
C3647053 | PMV15ENEA | Leiditech | SOT-23 |  | SOT-23 MOSFETs ROHS | yes | 15 | 5 | 0.0695 | 1.04 | https://assets.lcsc.com/images/lcsc/96x96/20220709_Leiditech-PMV15ENEA_C3647053_front.jpg
C150470 | DMG2305UX-7 | Diodes Incorporated | SOT-23(SOT-23-3) |  | 20V 4.2A 52mΩ@4.5V,4.2A 1.4W 900mV@250uA P Channel SOT-23(SOT-23-3) MOSFETs ROHS | yes | 5 | 5 | 0.0819 | 0.41 | https://assets.lcsc.com/images/lcsc/96x96/20180914_Diodes-Incorporated-DMG2305UX-7_C150470_front.jpg
C282260 | 2N7002_R1_00001 | PANJIT International | SOT-23 |  | 60V 250mA 5Ω@10V,500mA 350mW 2.5V@250uA N Channel SOT-23 MOSFETs ROHS | yes | 20 | 20 | 0.025 | 0.5 | https://assets.lcsc.com/images/lcsc/96x96/20180922_PANJIT-International-2N7002-R1-00001_C282260_front.jpg
C160404 | SM04B-SRSS-TB(LF)(SN) | JST Sales America | - |  | 1x4P 1 SR/SZ 1mm 4 Copper Alloy - Wire To Board / Wire To Wire Connector ROHS | yes | 5 | 5 | 0.1754 | 0.88 | https://assets.lcsc.com/images/lcsc/96x96/20180914_JST-Sales-America-SM04B-SRSS-TB-LF-SN_C160404_front.jpg
C429965 | 12251220ANG0S115001 | JILN | Straight,P=2.54mm |  | 3A Straight Square Pins 2.5mm 6mm -40℃~+105℃ 2 3mm 40 2.54mm Black Brass 2x20P 2.54mm Straight,P=2.54mm Pin Headers ROHS | yes | 5 | 5 | 0.1155 | 0.58 | https://assets.lcsc.com/images/lcsc/96x96/20191023_JILN-12251220ANG0S115001_C429965_front.jpg
C2685175 | PH-00650 | Liansheng | SMD,P=2.54mm |  | 3A Brick nogging Square Pins 2.5mm 6mm -40℃~+105℃ 2 40 2.54mm Black 2x20P 2.54mm SMD,P=2.54mm Pin Headers ROHS | yes | 10 | 5 | 0.2999 | 3 | https://assets.lcsc.com/images/lcsc/96x96/20210203_Liansheng-PH-00650_C2685175_front.jpg

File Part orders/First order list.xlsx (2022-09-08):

Component | Function | Order quantity | Link
TPS61169 | LED driver | 1 | https://nl.aliexpress.com/item/4000275000313.html?curPageLogUid=gA9T7z26nWtU
TPS61158 | LED driver | 1 | https://nl.aliexpress.com/item/1005003809491125.html?curPageLogUid=7M7p6VLxtnjE
TMC2209 | Stepper motor driver | 6 | https://nl.aliexpress.com/item/1005002965406330.html?curPageLogUid=vVAK5sJpMeMa
DRV8837 | Focussing lens motor driver | 1 | https://nl.aliexpress.com/item/1005004447321623.html?curPageLogUid=niIuQUdv4I7a
NONAME | stepdown buck converter 15W | 2 | https://nl.aliexpress.com/item/33013014541.html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
JCPOWER | 24V 10A PSU | 1 | https://nl.aliexpress.com/item/1720166296.html?_t=pvid%3A04d9b3f0-d7ec-497d-84ea-6b135fb970b9
 | stepper motor protector | 6 | https://nl.aliexpress.com/item/32917996858.html?gatewayAdapt=glo2nld

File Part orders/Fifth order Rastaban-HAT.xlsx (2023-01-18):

Bestelformulier
Let op: alleen volledig ingevulde formulieren worden in behandeling genomen.
Je bestellijst stuur je naar: | tom.franssen@han.nl | en een CC naar je docent
Je ontvangt op het door jou aangegeven email-adres een bericht wanneer je bestelling afgehaald kan worden
Naam | Artikel | Artikelnummer | Aantal | Leverancier | Prijs/st (excl BTW) | Totale kosten (excl BTW)
Jeroen Veen
Casper Tak | 2859146 | SRR1210-330M | 5 | Farnel | 1.26
 | 1808190 | 651-1808190 | 25 | Mouser | 0.91
 | 1778780 | 651-1778780 | 25 | Mouser | 1.61
 | 3020955RL | BCM53DSF | 15 | Farnel | 0.24
 | EDK227M050A9PAA | 80-EDK227M050A9PAA | 5 | Mouser | 0.89

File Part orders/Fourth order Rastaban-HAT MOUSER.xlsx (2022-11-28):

Bestelformulier
Let op: alleen volledig ingevulde formulieren worden in behandeling genomen.
Je bestellijst stuur je naar: | tom.franssen@han.nl | en een CC naar je docent
Je ontvangt op het door jou aangegeven email-adres een bericht wanneer je bestelling afgehaald kan worden
Naam | Artikel | Artikelnummer | Aantal | Leverancier | Prijs/st (excl BTW) | Totale kosten (excl BTW)
Jeroen Veen | DMG2305UX-7 (https://nl.mouser.com/ProductDetail/Diodes-Incorporated/DMG2305UX-7?qs=L1DZKBg7t5F%2FNBHrjfxC%252Bg%3D%3D) | 621-DMG2305UX-7 | 10 | Mouser | 0.42 | 4.2
Casper Tak | WSL1206R2000FTA | 71-WSL1206-0.2/R | 3 | Mouser | 1.45 | 4.35
 | 1709457 | 651-1709457 | 10 | Mouser | 0.97 | 9.7
 | 1709460 | 651-1709460 | 10 | Mouser | 1.72 | 17.2
 | 1808190 | 651-1808190 | 10 | Mouser | 0.91 | 9.1
 | 1778780 | 651-1778780 | 10 | Mouser | 1.61 | 16.1
 | ESD7351HT1G | 863-ESD7351HT1G | 20 | Mouser | 0.35 | 7
 |  |  |  |  |  | 0
 |  |  |  |  |  | 0
 |  |  |  |  |  | 0
 |  |  |  |  |  | 0
 |  |  |  |  |  | 0

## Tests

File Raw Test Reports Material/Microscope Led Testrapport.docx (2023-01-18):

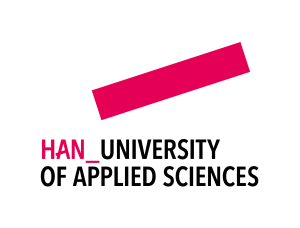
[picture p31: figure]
HAN University of Applied Sciences - Wikipedia

# Internship

TestReport

Microscope LED

Student: Casper R. Tak

Studentnumber: 657313

Client: Rudie van den Heuvel

Coach: Jeroen Veen

High School: HAN Arnhem

Education: Embedded Systems Engineering

Date: 07-11-2022

# Objective

The component that will be tested in this test report will be the microscope LED. This component is responsible for creating sufficient light for the camera module.

# Test Setup

- Testing equipment:
  - Hardware:
    - LabNation Cross Platform Oscilloscope
  - Software:
    - VSC
    - SSH connection to RPI
    - Smartscope
- Setup hardware/software

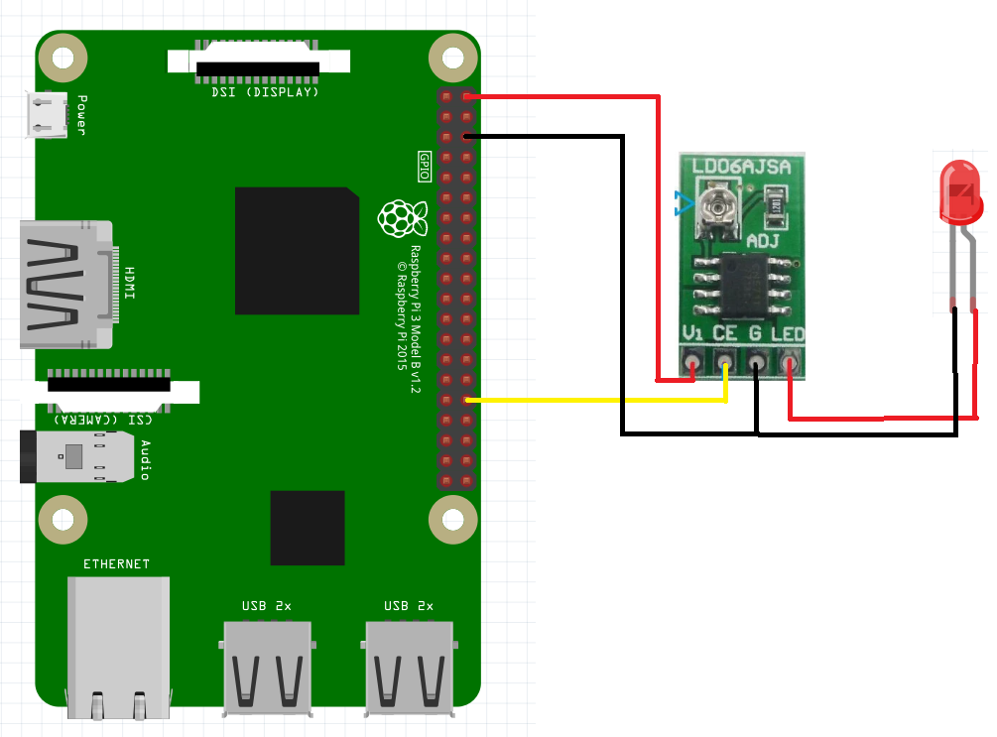
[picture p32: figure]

# Test Results

Test | Test passed if: | Observations | Test passed | Test Failed | Pictures | Notes

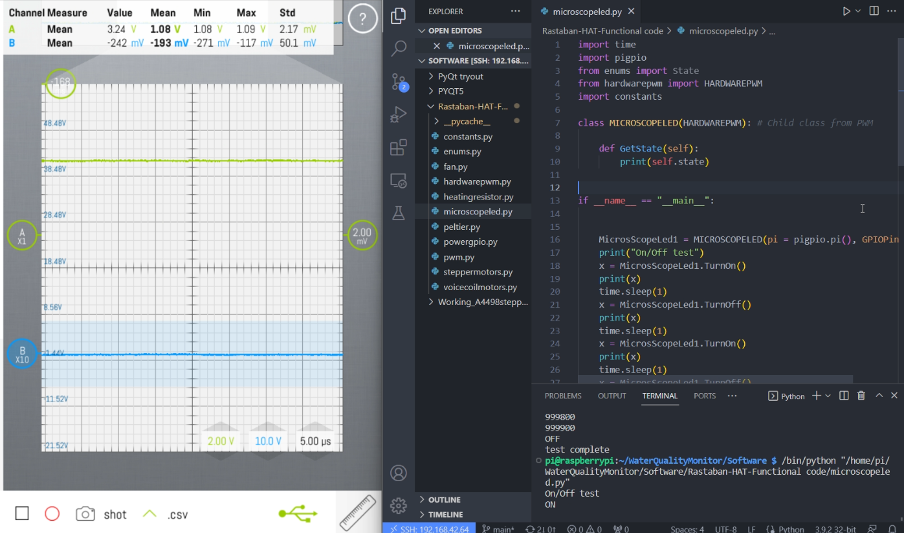
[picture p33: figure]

T1.0 | Device turns on | Device turns on | X

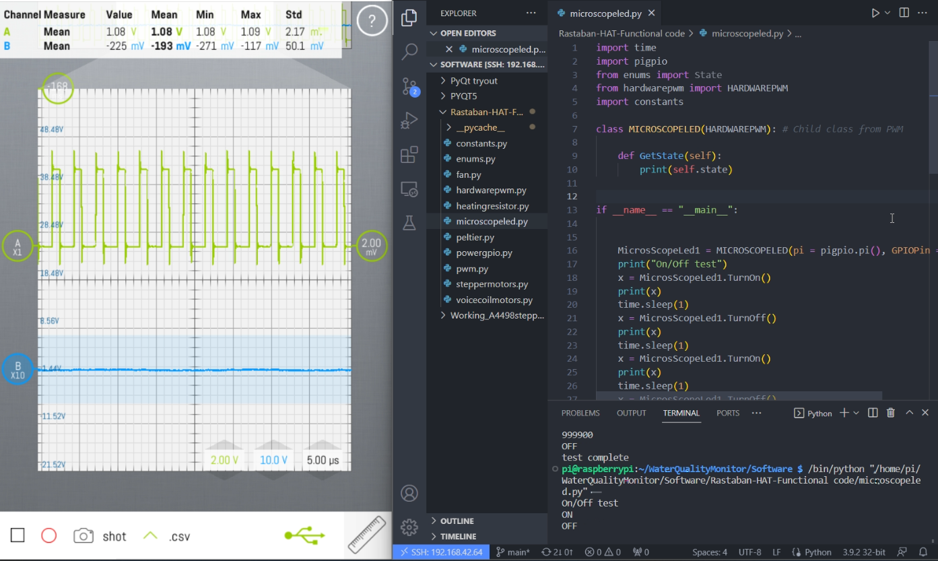
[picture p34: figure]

T1.1 | Device turns off | Device turns off | X | | | Expected 0V flat line, not this pwm wave

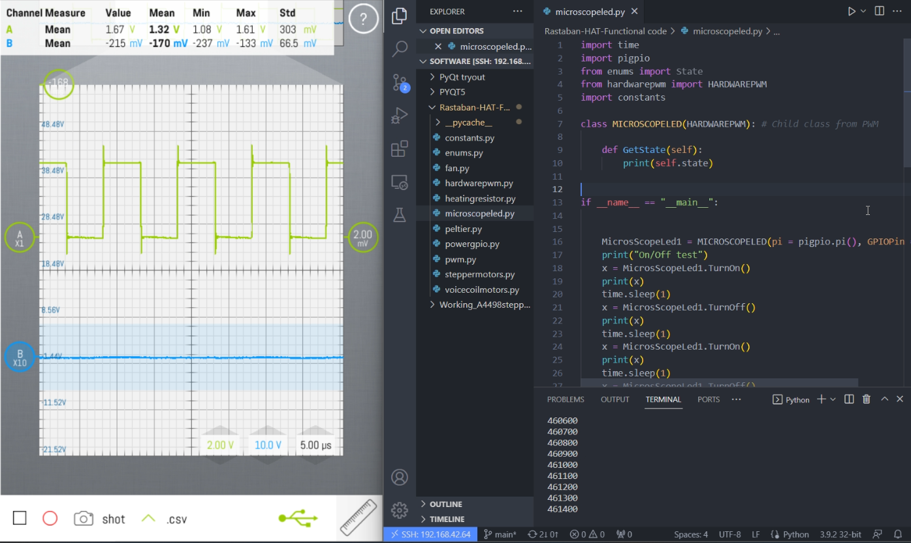
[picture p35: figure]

T1.2 | PWM control works | LED dims and brightens | X

# Conclusions

- The LED functions

# Further actions

- Since the LED seems to be turned off enough to not be visible for the human eye it may be enough to leave things as they are regarding this strange signal.

# Later discoveries

- We figured out that the reason for the signal not going to zero was because the value of 0, was not actually zero but around 35000hz by a constant. We changed the value to 0 and now it works fine.

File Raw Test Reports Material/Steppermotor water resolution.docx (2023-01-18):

HAN University of Applied Sciences - Wikipedia

# Internship

TestReport

Steppermotor water resolution

Student: Casper R. Tak

Studentnumber: 657313

Client: Rudie van den Heuvel

Coach: Jeroen Veen

High School: HAN Arnhem

Education: Embedded Systems Engineering

Date: 29-11-2022

# Objective

The component that will be tested in this test report will be the stepper motor resolution. This component is responsible for moving fluids from point a to point b.

Preliminary investigation

Inner volume of the pipe used is calculated using:

volume = π × (d²/4) × h

d = 1mm, h = 670mm

the volume will be: π × (1²/4) × 670 = 526.22 cu/mm (cubical mm)

or a total of 526 microliters will be in the clear part of the tube.

Now it is important to see how much degrees the motor has to rotate to move the water 1cm in the clear tube

volume = π × (d²/4) × h

d = 1mm, h = 10mm

the volume moved will be: π × (1²/4) × 10 = 7.85 cu/mm (cubical mm)

so 7.85 microliters is moved.

# Measuring options

Idea number | Idea details | expected benefits | expected drawbacks
1 | Check water flow through observation in clear tube | Easy set-up, no extra materials required | Eyes are not perfect, possible optical illusions and air in the tube can become a problem
2 | measure water droplets weight | More precise measuring using a high precision scale (no human reading errors) | Requires extra tools and droplets could get “stuck” in the end of the tube resulting in inconsistent measurements
3 | use flow sensor | Could be very precise, no issues with air or droplets that stay behind (like with the a scale | Errors in flow sensor (which is not really visible for user), difficult to see forward and backward flow, setup is time consuming

# Test Setup

- Testing equipment:
  - Hardware:
    - Zaleae Logic 16
    - TMC2209 stepper driver set to 64microstepping
    - BJ-RZ1030-4 stepper motor (12V)
  - Software:
    - VSC
    - SSH connection to RPI
    - Logic 2.3.45

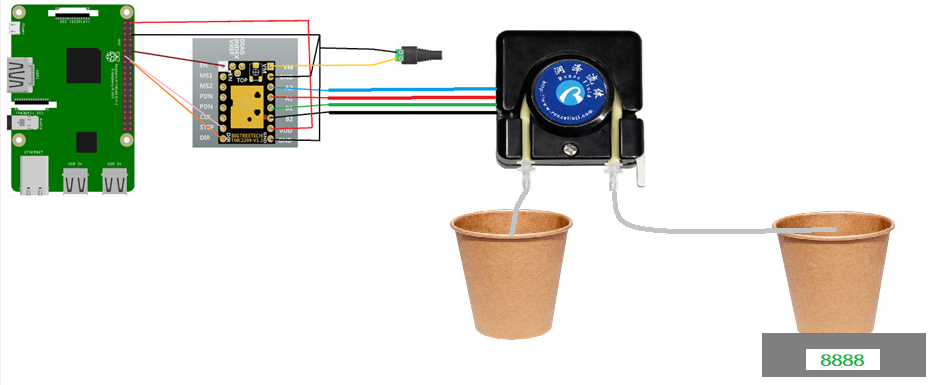
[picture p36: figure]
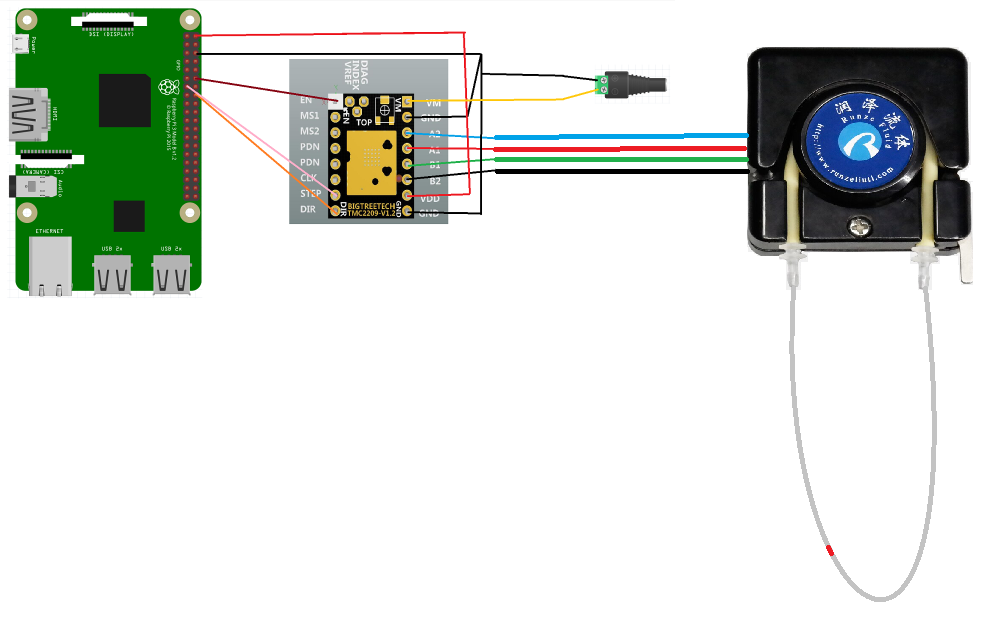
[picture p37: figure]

Hardware setup:
Test Results

Figure 2: Waterflow scale test

Figure 1: Water loop setup

Test (water loop) | Test passed if: | Observations | Test passed | Test Failed | Pictures | Notes
T1.0 | Water is contained and clearly flowing from point A to B in this form. | Water is mixing with the pigment, therefore it is not possible to see the exact water flow | | X
T1.1 | An “air train” or long air bubble is contained and clearly flowing from point A to B in this form. | The “air train” is not consistently flowing with the water, water passes the air. | | X

Test (Scale) | Test passed if: | Observations | Test passed | Test Failed | Pictures | Notes

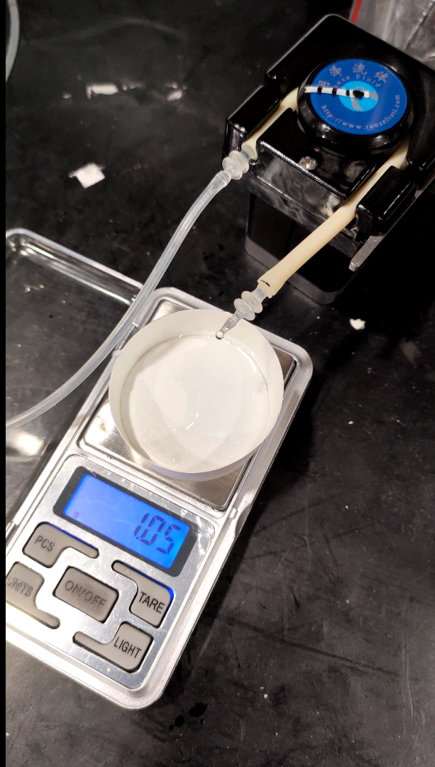
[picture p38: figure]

T1.0 | The weight on the scale increases with roughly the same step with every droplet added | The scale is showing a constant (Linear) increase every time the motor turn 360 degrees command is send | X

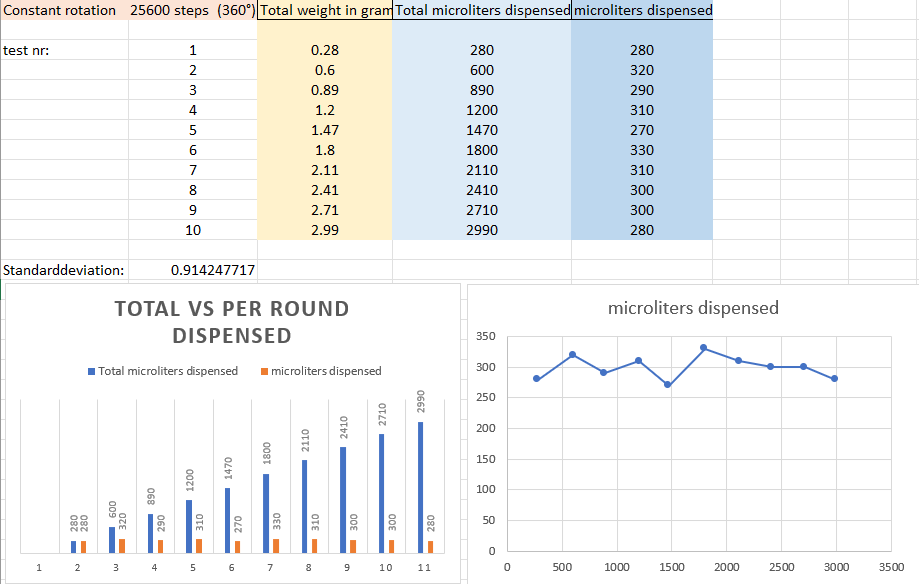
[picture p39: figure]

# Conclusions

- The water dispensing is quite accurate but I think that the mechanical part (the rollers on the tube) is creating a inconsistency in the dispense. This is most likely not something that can be resolved easily, since this is how to pump works. I suspect that the dispensing will become more unstable as the tube gets scratched time after time. Therefor I think it is wise to find an alternative pump or to use a flow sensor in combination with this pump (feedback) system. Another option is to use a syringe pump. This was already implemented in the S6 project from 2021. We could refine this pump system so it is significantly more compact.

# Further actions

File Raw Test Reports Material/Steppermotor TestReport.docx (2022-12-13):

HAN University of Applied Sciences - Wikipedia

# Internship

TestReport

Stepper motor

Student: Casper R. Tak

Studentnumber: 657313

Client: Rudie van den Heuvel

Coach: Jeroen Veen

High School: HAN Arnhem

Education: Embedded Systems Engineering

Date: 08-11-2022

# Objective

The component that will be tested in this test report will be the stepper motor. This component is responsible for moving fluids from point a to point b.

# Test Setup

- Testing equipment:
  - Hardware:
    - Zaleae Logic 16
  - Software:
    - VSC
    - SSH connection to RPI
    - Logic 2.3.45
- Setup hardware/software

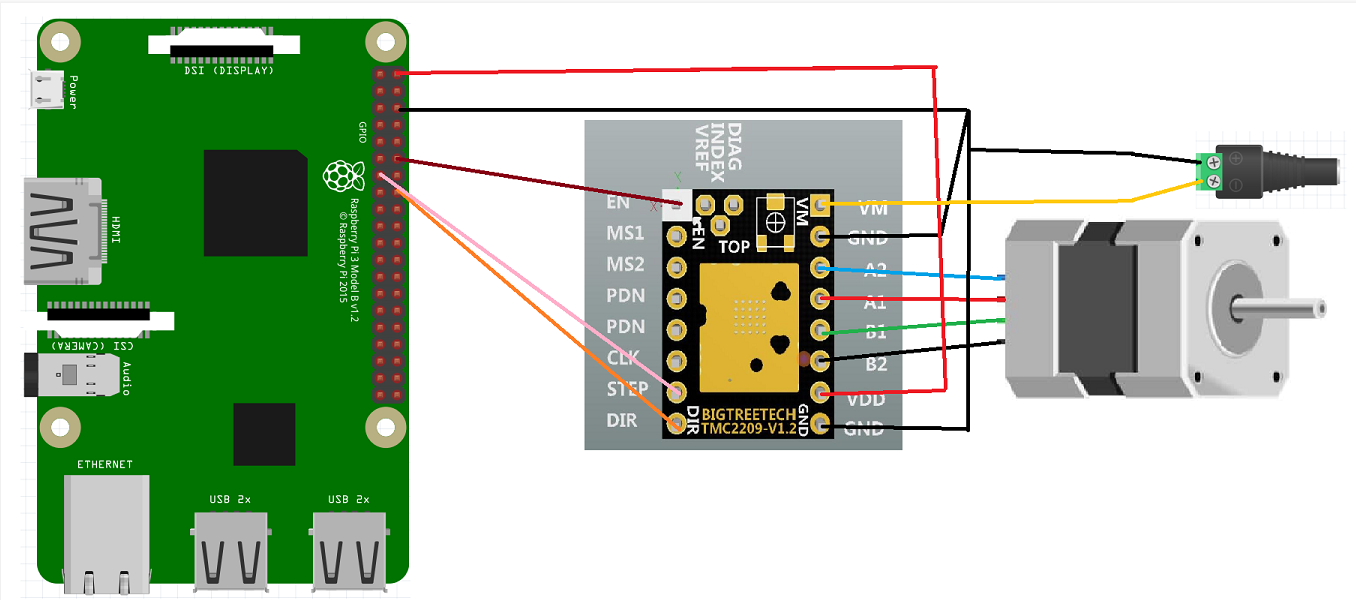
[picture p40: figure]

# Test1 Results

Test | Test passed if: | Observations | Test passed | Test Failed | Pictures | Notes
T1.0 | Motor torque increases when enabled | Motor shaft can’t be turned by hand anymore | X


T1.1 | Motor Torque decreases when disabled | Motor is stuttering | | X | | Motor control seems to be lost, motor cannot be turned off (enable pin is using pwm for some reason.)
T2.0 | Motor shaft turns clockwise | Motor is stuttering clockwise and anticlockwise | | X
T2.1 | Motor shaft turns counterclockwise | Motor is stuttering clockwise and anticlockwise | | X
T2.2 | Motor steps silently (silent stepping/micro stepping) | clockwise and anticlockwise, makes audible stutter noises | | X

# Conclusions

- The motor is not controlled correctly, something is wrong in either the software, connections (breadboard) or pigpio library, I expect the first.

# Further actions

- I will try to find bugs in the software and strip down the test to enable and disabling the motor only. Ask teacher for help if needed. Then I will do new tests.
- New discoverys: it seems that the DMA controller or maybe a background process from pigpio keeps running the code somehow. By setting the pin as an input it does put the pin on LOW. By putting it back as output (as shown below) the pin becomes high again, so somehow the old program keeps running.
- Changing pins or using write functions doesn’t seem to fix anything. I compared the hardware pwm and software pwm but all seems to be basically the same.


Daemon causes issues. Because when we restart the daemon everything works. Removing the -l doesn’t work.


Solution: we settled on disabling the automatic start of the daemon on boot. I now manually start pigpiod when I run my program, so not at boot.

Check status: systemctl status pigpiod

Stop pigpiod: systemctl stop pigpiod

Test | Test passed if: | Observations | Test passed | Test Failed | Pictures | Notes
T1.0 | Motor torque increases when enabled | Motor shaft can’t be turned by hand anymore | X
T1.1 | Motor Torque decreases when disabled | Motor is stuttering | X


T2.0 | Motor shaft turns clockwise | Motor shaft turns clockwise | X
T2.1 | Motor shaft turns counterclockwise | Motor shaft turns counterclockwise | X
T2.2 | Motor steps silently (silent stepping/micro stepping) | Motor turns near silently | X

# Test2 Results

# Conclusions

- The motor is now running the way it should. It’s resolution could be improved by switching from 1/16 micro stepping to 1/64. To achieve this on the PCB, we need to add resistor pads to ms1, ms2.

# Further Actions

- After some more research it was found that using the UART function of the TMC2209 gives us much more accuracy and control over the data going in and out of the drivers. Redesign V0.3 of the Rastaban Hat will therefore only use UART to control the drivers.

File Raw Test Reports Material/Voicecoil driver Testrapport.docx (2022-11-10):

HAN University of Applied Sciences - Wikipedia

# Internship

TestReport

Voicecoil driver

Student: Casper R. Tak

Studentnumber: 657313

Client: Rudie van den Heuvel

Coach: Jeroen Veen

High School: HAN Arnhem

Education: Embedded Systems Engineering

Date: 09-11-2022

# Objective

The component that will be tested in this test report will be the voice coil driver (DRV8838). This component is responsible for driving the voice coil up and down to focus the lens of the camera.

# Test Setup

- Testing equipment:
  - Hardware:
    - Zaleae Logic 16
  - Software:
    - VSC
    - SSH connection to RPI
    - Logic 2.3.45
- Setup hardware/software


# Test Results

Test | Test passed if: | Observations | Test passed | Test Failed | Pictures | Notes


T1.0 | Driver gets disabled | Logic analyzer shows LOW on sleep pin | X | | | Phase pin was undefined, can be ignored


T1.1 | Driver gets enabled | Logic analyzer shows HIGH on sleep pin | X
T2.0 | Motor shaft turns clockwise | Motor turns clockwise | X


T2.1 | Motor shaft turns counterclockwise | Motor turns counter clockwise, phase changes | X


T2.2 | Variable speed control | Motor turns at a different speed (increasing) | X

# Conclusions

- The driver seems to be functioning correctly. The motor is driving the way it is intended to with variable speed an direction options.

# Further actions

- There is an error on the schematic for the PCB design -> VCC is not connected, however it should be connected to 3.3V or 5V for the driver to function.

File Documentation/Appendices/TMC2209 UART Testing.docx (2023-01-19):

# 1 UART Problem with multiple drivers

When connection multiple drivers you are able to read/write commands to the drivers individually using the same bidirectional line.

Strangely enough I could not figure out why the above configuration did not work.


I configured one driver to be 01 and the other 00 by connection the ms1 and ms2 to GND and VCC the way it was shown in figure 4.1 above. Somehow I always get this message:


These are the configurations I tested with:

| PDN UART | TMC software address settings | Result | Additional notes
TMC driver A | Connected to RX | 1 | Functional | Changing one address to 0 also makes it NOT functional
TMC driver B | Floating | 1
TMC driver A | Floating | 0 | Functional
TMC driver B | Connected to RX | 0
TMC driver A | Connected to RX | 0 | NOT Functional
TMC driver B | Floating | 1
TMC driver A | Floating | 0 | NOT Functional
TMC driver B | Connected to RX | 1


First Conclusion/solution

The driver UART control only works if there is one driver connected to RX and assigned address to this driver is selected in software (according to the ms1 + ms2 settings you chose). You can however use 2 drivers if you go with the “more than 4 drivers solution” which Trinamic provided. This could be achieved with transistors as well I suppose.

If reading from the driver is not required, using the write only function as seen in figure 4.1 of the datasheet is a viable option. This way we only need to use n+1 pins of the raspberry pi to control the motors, where n increases with every driver added (enable pin). This would treat all steppers as the same and would control them using the enable pin and sending data over the RX pin.

# 2 Further testing UART communication TMC2209

Configuration (test script 05: vactual.py) RX and TX are flipped in the pictures:


This is what a successful transmission, with a few rotations and direction changes should look like.

When zoomed in it is clear that the TX deviates from the RX line data.


Further inspection shows that it does sometimes match the RX line

It is however always the case that TX continues sending after RX is done with a package.

It is however always the case that TX continues sending after RX is done with a package.

Using these settings (test script 06: multiple drivers.py) RX and TX are flipped in the picture:


This is what a unsuccessful transmission looks like:

When zoomed in it seems that TX receives exactly the same information as it sends out. While, as stated earlier, it is expected that TX sends more data after RX is finished.

### 2.1.1 Second conclusion and solution for the UART error

I can conclude that somehow TX is getting the same information as it sends out on the RX line.

With the help of Thomas Ijsseldijk we found the cause and the fix for this problem. Lowering the TX resistor to 500ohms (from 1k) increases the voltage available for the IO of the TMC driver which results in the TMC being able to read the signal. It appears to be very important to choose the right resistor value. It is now possible to control the stepper motors via UART. This reduces the pins required on the raspberry pi with 7 pins (removing all step and dir pins)

The final configuration for the stepper motor drivers is as following:


We decided to go with the TMC2209 and we operate it in UART mode only. This means we need to connect to PDN UART and use one enable pin per driver to select it. The jumpers are there to select the driver address (up to 4 drivers in total).

### 2.1.2 Final conclusions

After having spend days debugging the hardware; checking continuity, isolating components, swapping resistors values, and rebuilding my original test setup I can conclude that I never had a UART connection to begin with. What exactly happened when the motors started driving is not clear to me. This answer lays in the library.

What I do know is that the TMC2208 driver that we used (the old driver) had a solder jumper that was not soldered. A really strange decision by the manufacturer. When the solder connection was made, UART was functional. That was the only hardware problem relating UART. Now the software was where the real problem was.

We needed to disable the system service that initializes the modem, so it does not connect to the first PL011 (UART0; /dev/ttyAMA0). In the command line:

$sudo systemctl disable hciuart

And further we (only!) disabled the login shell on the serial port in the interfacing options of "sudo raspi-config", and rebooted the system.

When we started the UART test script for the tmc2209, we immediately got everything working. We than tested 2 drivers and got the same result:


The extra resistors added to UART per driver was also proven to be a myth. 2 drivers can communicate perfectly fine with a 1K resistor only.

## 2.1 Motor stutter issue

After having fixed the communication error with UART another problem occurred: the motors would start to stutter, switch direction randomly or stall and vibrate.

I tried debugging this following the following plan:

1. Check the hardware: is everything connected like it should be?
  a. This was the case, everything had power (since uart connections works) and I powered everything via the VM pin and I knew VIO is getting its power via this pin as well.
  b. The motor is connected to the connector and there is continuity
2. Measure signals: is there even a signal coming out of the driver?
  a. Yes, I connected my logic analyser to the primary stepper motor connector and got 4 signals when I send the vactual movement test command.
3. Is the signal that is transmitted to the motor the right one? Maybe the motor receives something it cannot work with.
  a. I had to check this I did this by using step and dir on an external tmc2209 and captured the signal. The motor rotated fine when using my old testsketch and I recorded the signal going to the 4 motor wires. This is the signal I require (or something that at least looks like it)
  b. Then I compared it to the output to 4 motor wires coming from the pcb. This looked very different. Later I figured out it may had something to do with a broken driver. 2 outputs where as expected, but the other 2 where not.
4. Is the motor connector wiring on the PCB to the connector the way I think it is.
  a. I should have checked this first! This was NOT the case! I expected the output from the connector to the driver to be M1A, M1B, M2A, M2B but it was not! The pairs on the connector where not AA,BB but ABAB This means that I connected the motor wires wrong and therefor the motor would not rotate correctly.
5. If one motor works, does the other work too?
  a. No, when connecting a second driver and a stepper motor to the second port and changing the enable pin to the second motor pin, I got an communication error (0,4) I quickly figured that I had to give an extra parameter to tmc object I created in my code: tmc = TMC_2209(22, driver_address=1) where I configured the jumpers on my PCB (address selectors) to be 0 for the primary driver, 1 for the secondary driver and 2 for the third driver. After having added this, I can successfully control 3 motors apart from each other.

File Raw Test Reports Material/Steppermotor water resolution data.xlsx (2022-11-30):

Constant rotation | 25600 steps (360°) | Total weight in gram | Total microliters dispensed | microliters dispensed
test nr: | 1 | 0.28 | 280 | 280
 | 2 | 0.6 | 600 | 320
 | 3 | 0.89 | 890 | 290
 | 4 | 1.2 | 1200 | 310
 | 5 | 1.47 | 1470 | 270
 | 6 | 1.8 | 1800 | 330
 | 7 | 2.11 | 2110 | 310
 | 8 | 2.41 | 2410 | 300
 | 9 | 2.71 | 2710 | 300
 | 10 | 2.99 | 2990 | 280
Standarddeviation: | 0.9142477175

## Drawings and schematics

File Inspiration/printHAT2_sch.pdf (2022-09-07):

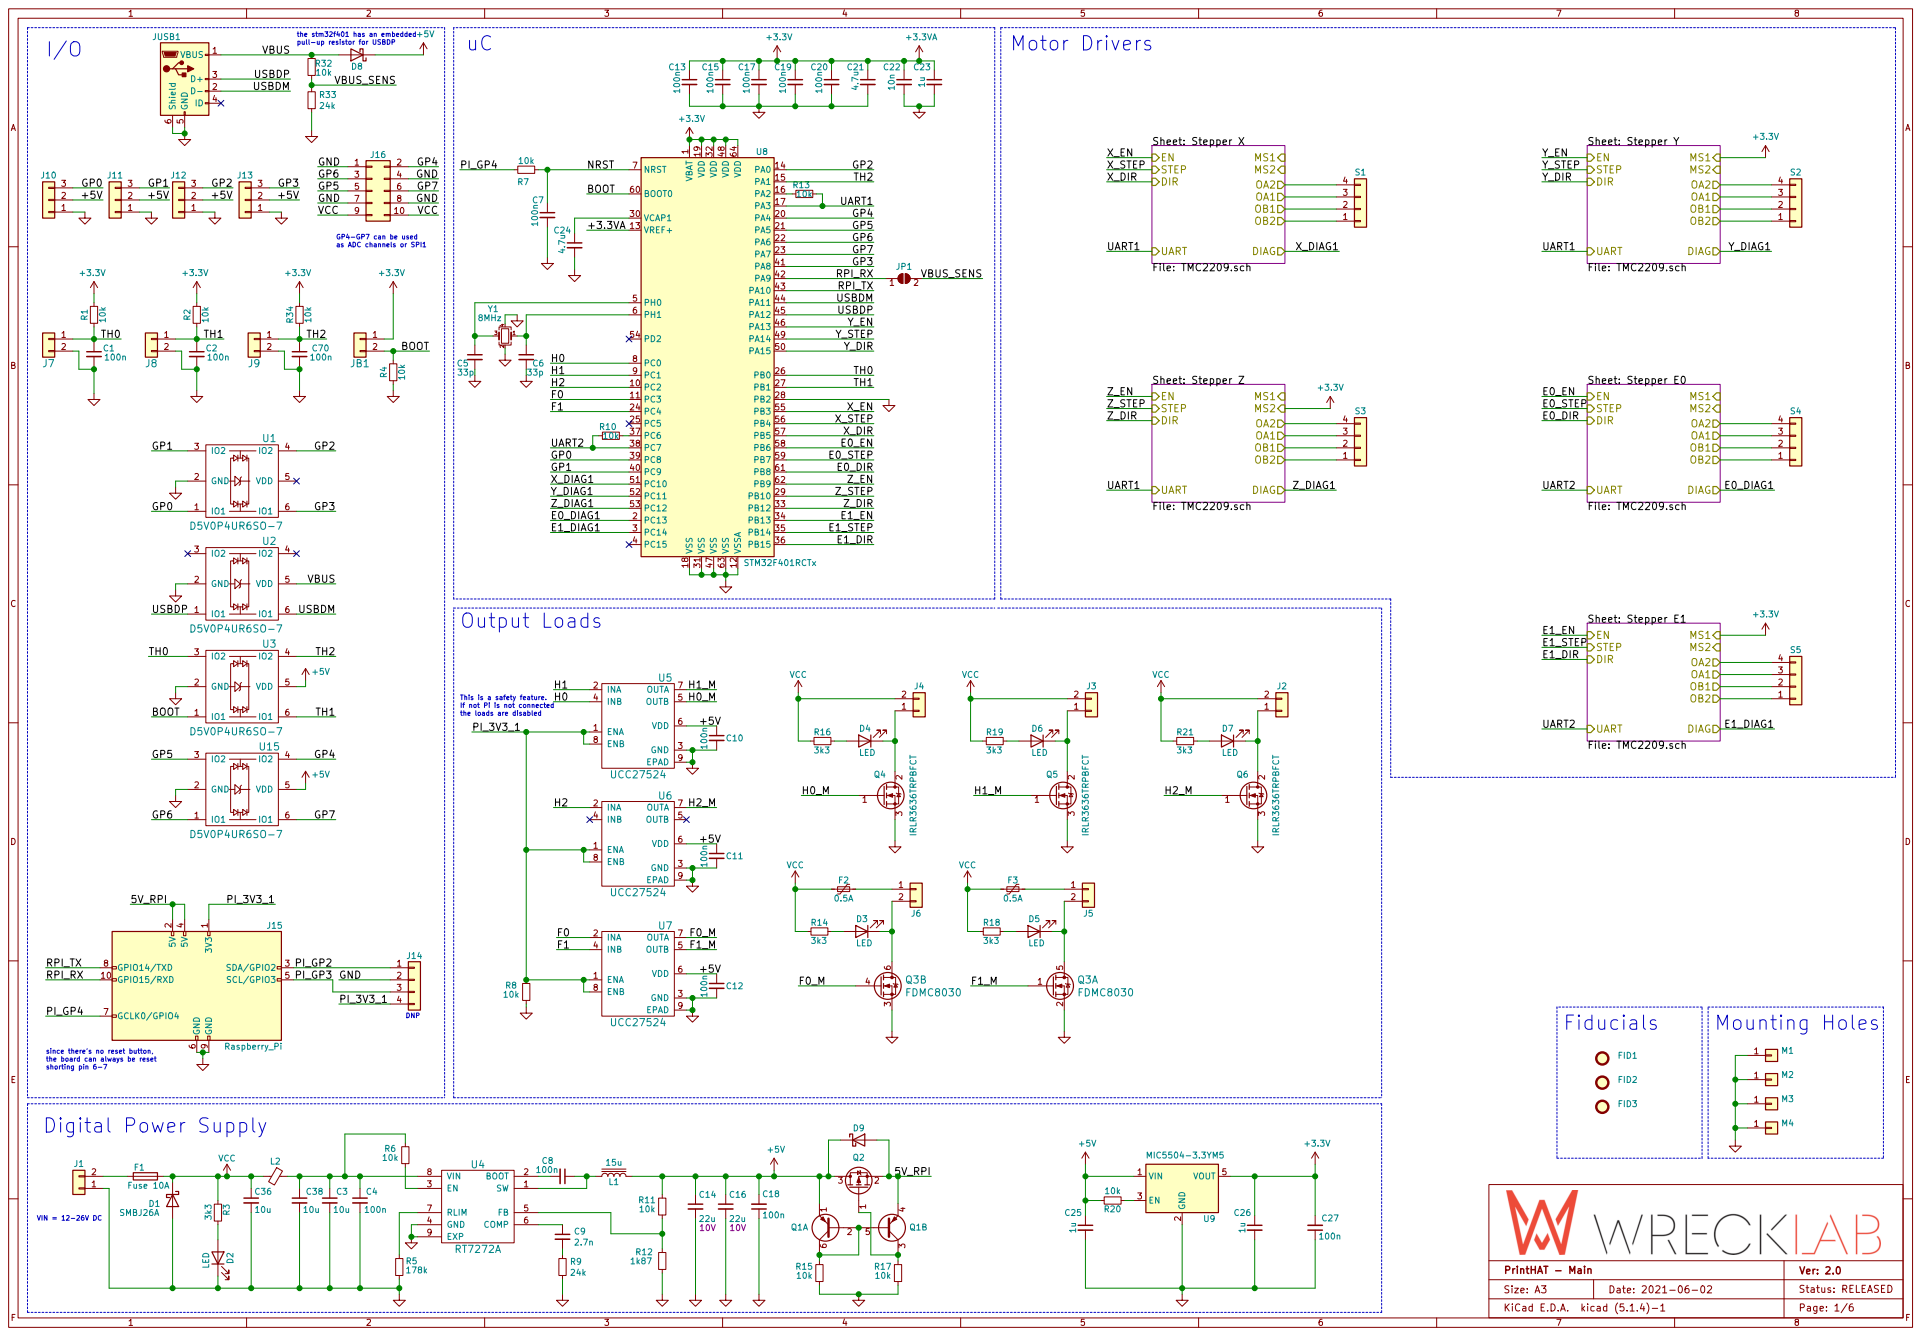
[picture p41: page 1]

the stm32f401 has an embedded
VBUS

the loads are disabled uC

GP4-GP7 can be used as ADC channels or SPI1 I/O

1 VCAP1 30 VDD 19 VDD 32 VDD 48 VDD 64 VREF+ 13 VSS 18 VSS 31 VSS 47 VSS 63 VSSA 12 U8 STM32F401RCTx

E1_DIR

This is a safety feature.
If not Pi is not connected

since there's no reset button,
the board can always be reset shorting pin 6-7

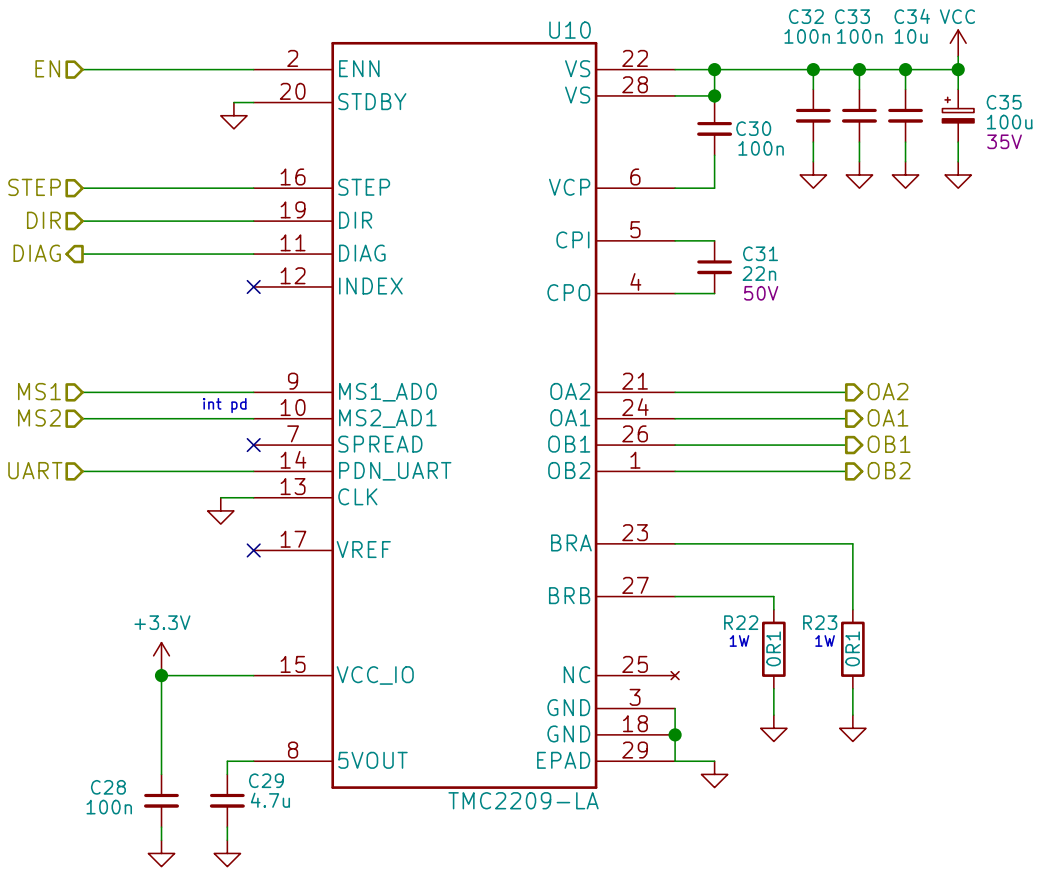
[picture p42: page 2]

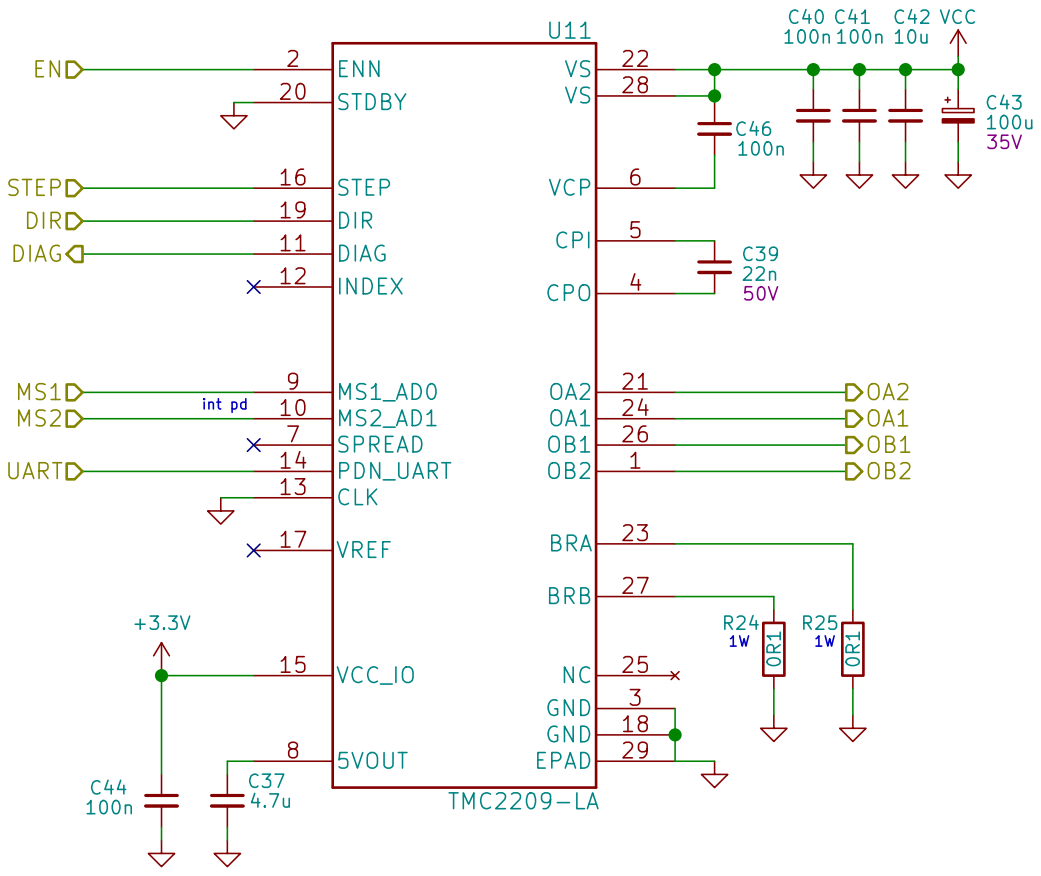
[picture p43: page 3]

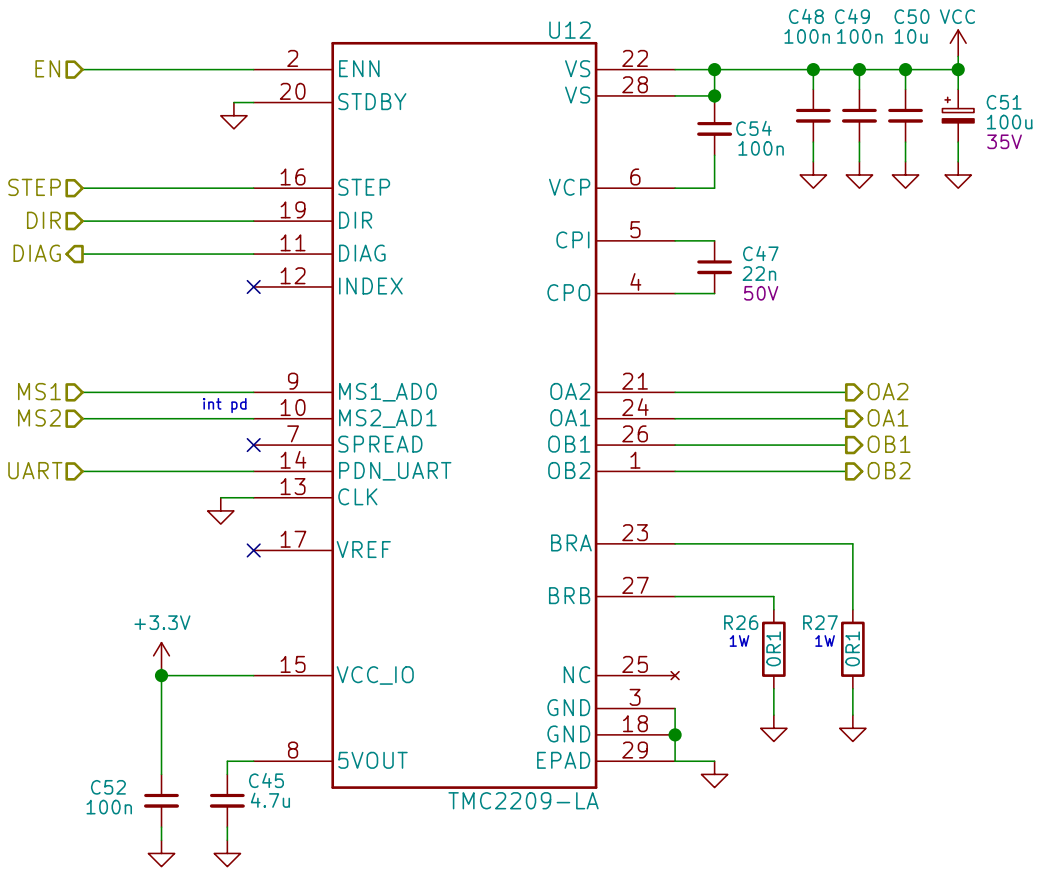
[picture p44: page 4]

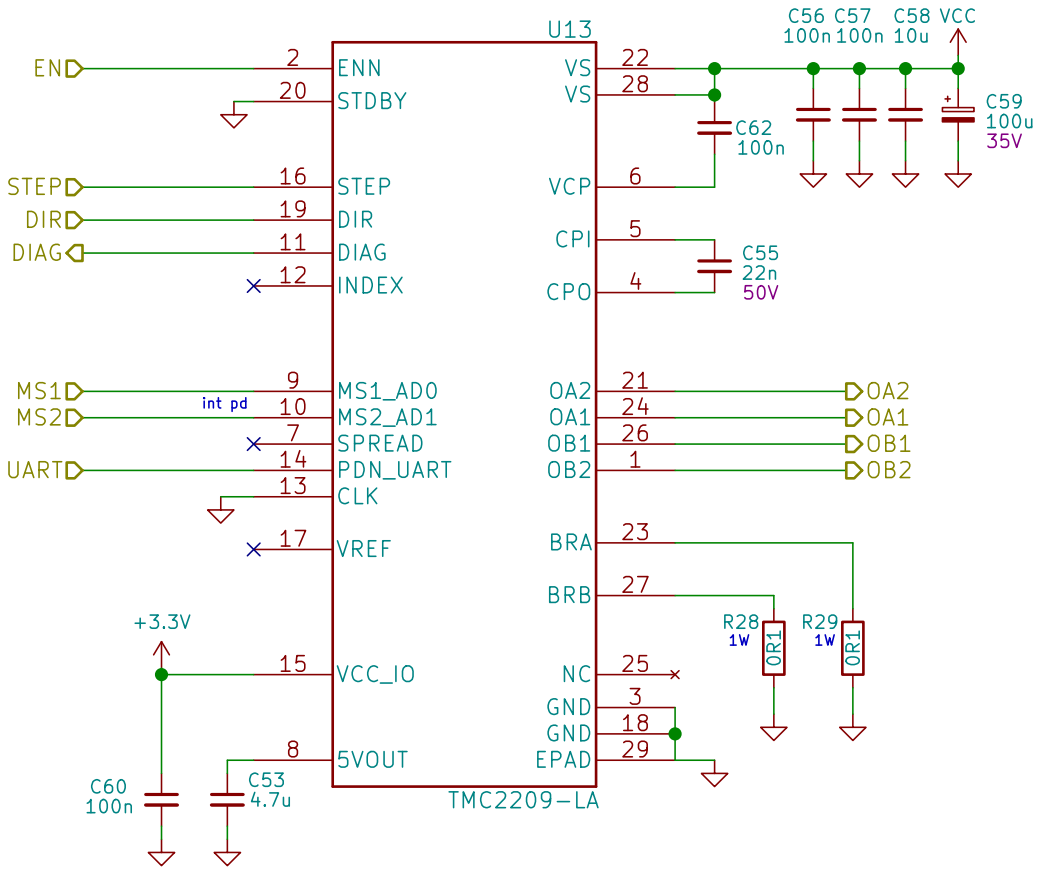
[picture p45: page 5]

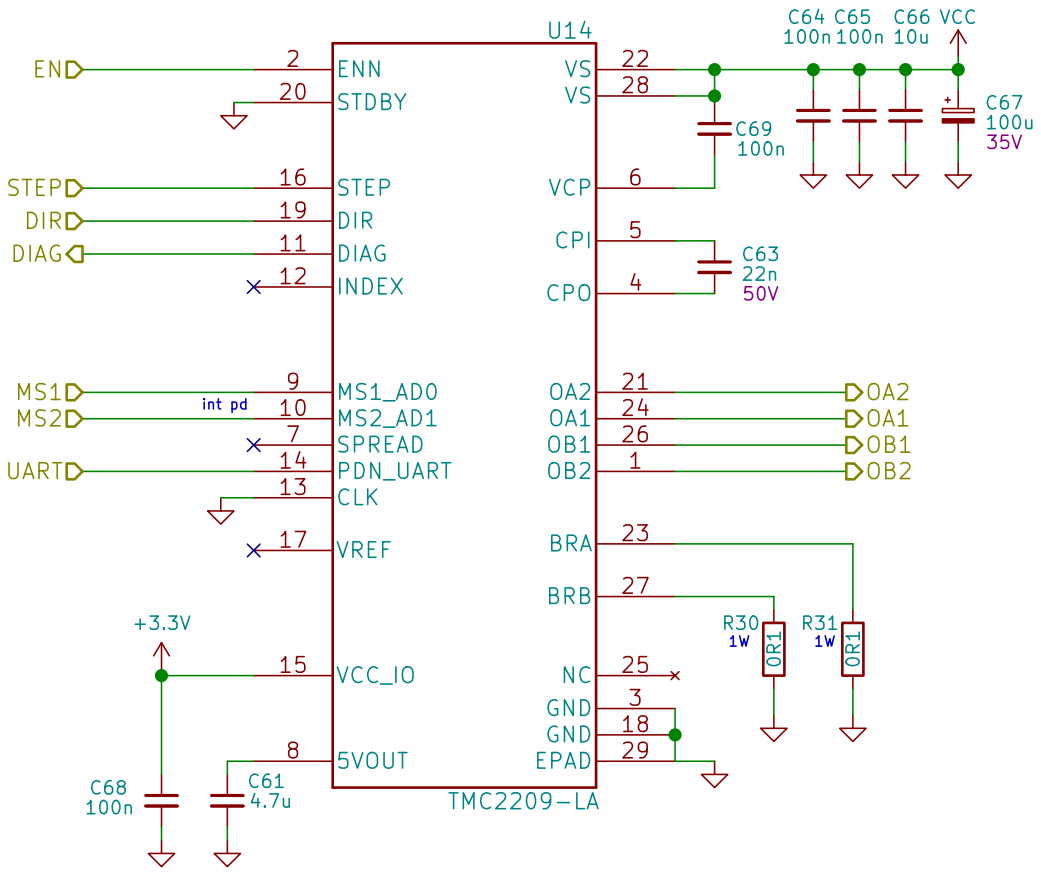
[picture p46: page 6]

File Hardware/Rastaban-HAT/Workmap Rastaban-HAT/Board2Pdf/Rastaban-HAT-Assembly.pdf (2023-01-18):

1 | 2 | 3 | 4 | 5 1 | 2 | 3 | 4 | 5 ABCD | ABCD Date: 2022-12-20 KiCad E.D.A. kicad (6.0.6) Size: User | Rev: V0.3.1

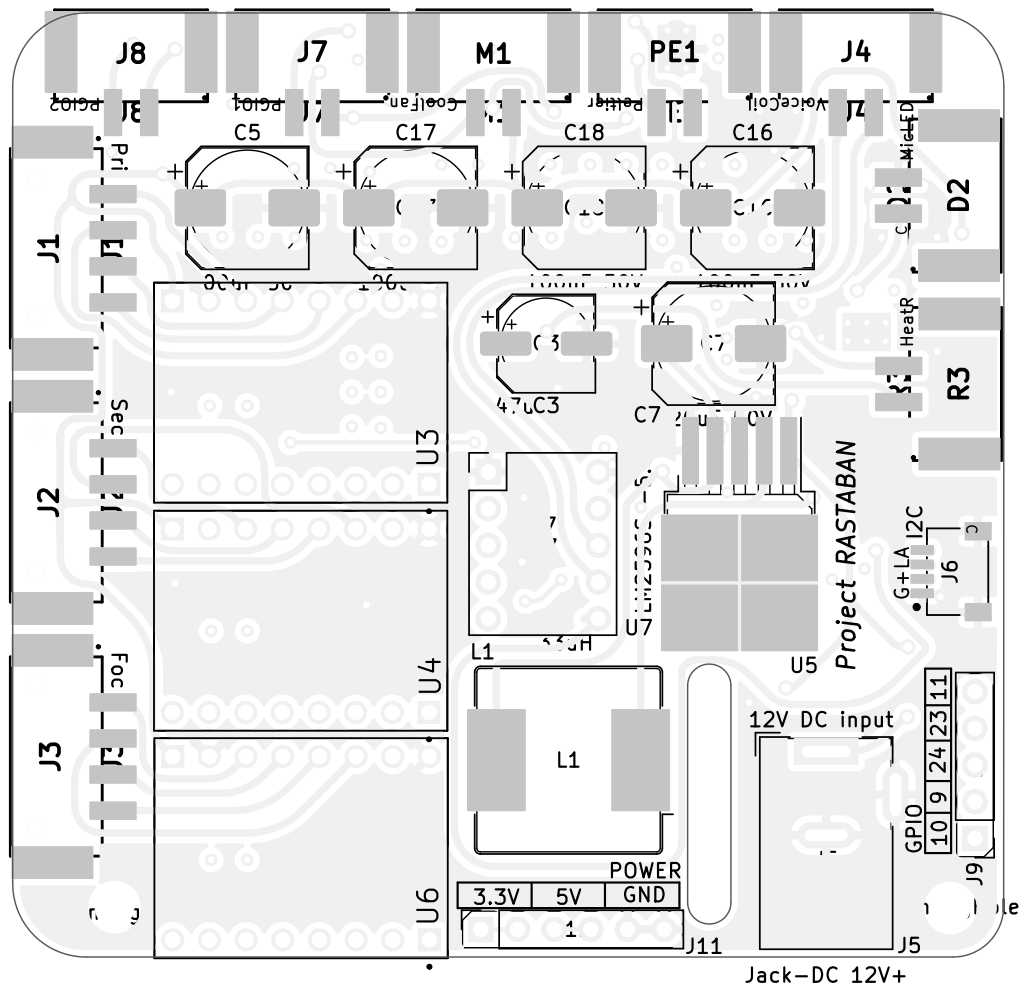
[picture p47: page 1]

5V
J11

Designed by: Casper R. Tak
Sheet: BlackAndWhiteTop HAN

File: Rastaban-HAT.kicad_pcb
Id: 1/1 Title: Rastaban-RPI-HAT

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

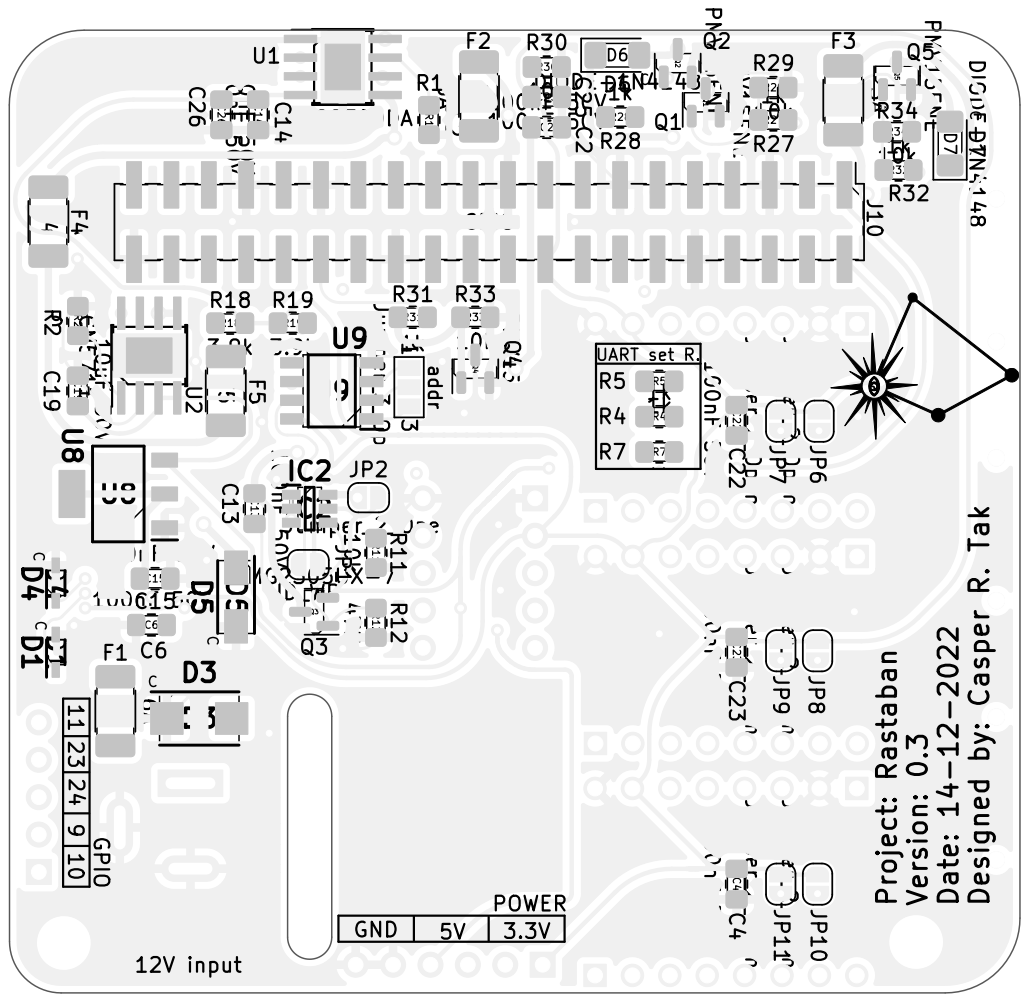
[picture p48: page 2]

HAN
File: Rastaban-HAT.kicad_pcb Sheet: BlackAndWhiteBottom
Id: 1/1 Title: Rastaban-RPI-HAT

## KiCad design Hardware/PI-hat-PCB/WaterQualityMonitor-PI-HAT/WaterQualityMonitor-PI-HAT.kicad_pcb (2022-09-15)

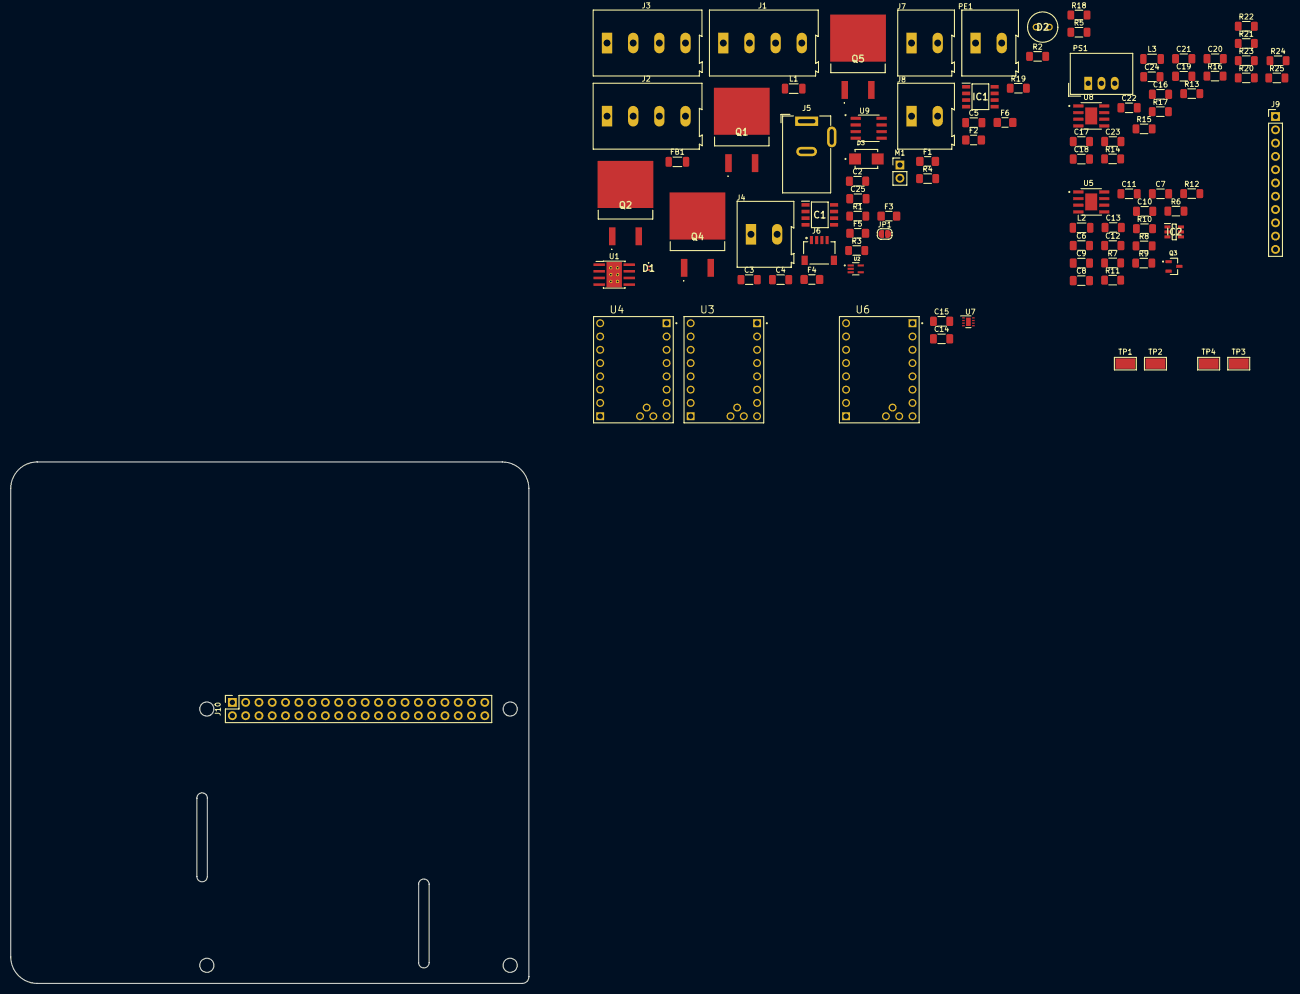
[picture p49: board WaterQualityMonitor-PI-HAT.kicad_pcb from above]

Board: 2 copper layers, 99.1 x 99.7 mm, 101 parts (0 on the bottom side), 91 nets, no tracks yet.

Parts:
C1: 10uF; SOIC127P600X175-8N
C2, C14, C15: 0.1uF; C_1206_3216Metric_Pad1.33x1.80mm_HandSolder
C3: 47uF; C_1206_3216Metric_Pad1.33x1.80mm_HandSolder
C4: 4.7uF; C_1206_3216Metric_Pad1.33x1.80mm_HandSolder
C5, C6, C7, C8, C16, C17, C18: 10u; C_1206_3216Metric_Pad1.33x1.80mm_HandSolder
C9, C19: 2.7n; C_1206_3216Metric_Pad1.33x1.80mm_HandSolder
C10, C13, C20, C23, C24, C25: 100n; C_1206_3216Metric_Pad1.33x1.80mm_HandSolder
C11, C12, C21, C22: 22u 10V; C_1206_3216Metric_Pad1.33x1.80mm_HandSolder
D1: SESD0402X1UN-0020-090; SESD0402X1UN0020090
D2: OVLEW1CB9
D3: SMBJ26A; DIOM4336X265N
F1: 0.5A; Fuse_1206_3216Metric_Pad1.42x1.75mm_HandSolder
F2: 4A; Fuse_1206_3216Metric_Pad1.42x1.75mm_HandSolder
F3, F5, F6: 3.2A; Fuse_1206_3216Metric_Pad1.42x1.75mm_HandSolder
F4: 10A; Fuse_1206_3216Metric_Pad1.42x1.75mm_HandSolder
FB1: 150uH; L_1206_3216Metric_Pad1.22x1.90mm_HandSolder
IC1: P82B96TD,118; SOIC127P600X175-8N
IC2: DMMT5401-7-F; SOT95P285X140-6N
J1, J2, J3: Screw_Terminal_01x04; TerminalBlock_Altech_AK300-4_P5.00mm
J4, J7, J8: Screw_Terminal_01x02; TerminalBlock_Altech_AK300-2_P5.00mm
J5: Jack-DC 12V+; BarrelJack_Wuerth_6941xx301002
J6: SM04B-SRSS-TB(LF)(SN); JST_SM04B-SRSS-TB(LF)(SN)
J9: Conn_01x11_Male; PinHeader_1x11_P2.54mm_Vertical
J10: GPIO; PinSocket_2x20_P2.54mm_Vertical
JP1: ID_WP; SolderJumper-2_P1.3mm_Open_RoundedPad1.0x1.5mm
L1: 4.7uH; L_1206_3216Metric_Pad1.22x1.90mm_HandSolder
L2, L3: 15u; L_1206_3216Metric_Pad1.22x1.90mm_HandSolder
M1: Fan; PinHeader_1x02_P2.54mm_Vertical
MH1, MH2, MH3, MH4: MountingHole_2.7mm_M2.5
PE1: PeltierElement; TerminalBlock_Altech_AK300-2_P5.00mm
PS1: TSR_2-2433; Converter_DCDC_TRACO_TSR-1_THT
Q1, Q2, Q4, Q5: IRL540SPBF
Q3: DMG2305UX-7; SOT91P240X110-3N_DMG2305UX-7
R1: 0.2; R_1206_3216Metric_Pad1.30x1.75mm_HandSolder
R2: 5.1; R_1206_3216Metric_Pad1.30x1.75mm_HandSolder
R3: 1.20KOHM-0603-1_10W-1%; R_1206_3216Metric_Pad1.30x1.75mm_HandSolder
R4, R5: 10K; R_1206_3216Metric_Pad1.30x1.75mm_HandSolder
R6, R13: 178k; R_1206_3216Metric_Pad1.30x1.75mm_HandSolder
R7, R15: 24k; R_1206_3216Metric_Pad1.30x1.75mm_HandSolder
R8, R10, R11, R14, R16: 10k; R_1206_3216Metric_Pad1.30x1.75mm_HandSolder
R9, R17: 1k87; R_1206_3216Metric_Pad1.30x1.75mm_HandSolder
R12: 47K; R_1206_3216Metric_Pad1.30x1.75mm_HandSolder
R18, R19: 3.9k; R_1206_3216Metric_Pad1.30x1.75mm_HandSolder
R20, R21, R22, R23, R24, R25: 22k; R_1206_3216Metric_Pad1.30x1.75mm_HandSolder
TP1, TP2, TP3, TP4: TestPoint; TestPoint_Keystone_5019_Minature
U1: DRV8870DDA; Texas_HTSOP-8-1EP_3.9x4.9mm_P1.27mm_EP2.95x4.9mm_Mask2.4x3.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
U2: TPS61169DCKR; SOT65P210X110-5N
U3, U4, U6: TMC2208_SILENTSTEPSTICK
U5, U8: RT7272AGSP; SOIC127P599X175-9N
U7: DRV8838; WSON-8-1EP_2x2mm_P0.5mm_EP0.9x1.6mm
U9: CAT24C256; SOIC127P600X175-8N

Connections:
3.3V: C14.2, IC1.8 (VCC), J6.2, PS1.3 (+VOUT), R4.1, R5.2, R20.2, R21.2, R22.2, R23.2, R24.2, R25.2, U1.4 (VREF), U3.JP2_7 (VIO), U3.VREF, U4.JP2_7 (VIO), U4.VREF, U6.JP2_7 (VIO), U6.VREF, U7.7 (~SLEEP), U7.8 (VCC)
5V: C1.1, C21.2, C22.2, C23.2, C24.1, L1.1, L3.2, PS1.1 (+VIN), R16.1, U2.5 (VIN)
5VRPI: IC2.5 (E2), J10.2, J10.4, Q3.2
12V+: C6.1, C7.1, C8.1, C15.2, C16.1, C17.1, C18.1, F1.1, F2.1, F3.1, F5.1, F6.1, FB1.2, R10.1, R14.1, U3.JP2_1 (VM), U4.JP2_1 (VM), U5.8 (VIN), U6.JP2_1 (VM), U7.1 (VM), U8.8 (VIN)
12VIN: F4.1, J5.1
+3V3: C25.1, JP1.2 (B), R18.1, R19.1, U9.8 (VCC)
/FluidMotors/OA1MAIN: J1.1, U3.JP2_4 (OA1)
/FluidMotors/OA1SEC: J2.1, U4.JP2_4 (OA1)
/FluidMotors/OA2MAIN: J1.2, U3.JP2_3 (OA2)
/FluidMotors/OA2SEC: J2.2, U4.JP2_3 (OA2)
/FluidMotors/OB1MAIN: J1.3, U3.JP2_5 (OB1)
/FluidMotors/OB1SEC: J2.3, U4.JP2_5 (OB1)
/FluidMotors/OB2MAIN: J1.4, U3.JP2_6 (OB2)
/FluidMotors/OB2SEC: J2.4, U4.JP2_6 (OB2)
/FocusMotors/OA1FOCUS: J3.1, U6.JP2_4 (OA1)
/FocusMotors/OA2FOCUS: J3.2, U6.JP2_3 (OA2)
/FocusMotors/OB1FOCUS: J3.3, U6.JP2_5 (OB1)
/FocusMotors/OB2FOCUS: J3.4, U6.JP2_6 (OB2)
/FocusMotors/out1: J4.1, U7.2 (OUT1)
/FocusMotors/out2: J4.2, U7.3 (OUT2)
/ID_SCL: J10.28, R19.2, U9.6 (SCL)
/ID_SDA: J10.27, R18.2, U9.5 (SDA)
CTRLFAN: J10.31, Q1.1
CTRLHEAT: J10.29, Q2.1
CTRLLED: J10.12, U2.4 (CTRL)
DIRFOCUS: J10.37, U6.JP1_1 (DIR)
DIRMAIN: J10.16, U3.JP1_1 (DIR)
DIRSEC: J10.15, U4.JP1_1 (DIR)
ENDRV: J10.32, U7.5 (EN)
GND: C1.2, C2.1, C3.1, C4.2, C5.2, C6.2, C7.2, C8.2, C11.1, C12.1, C13.1, C14.1, C15.1, C16.2, C17.2, C18.2, C21.1, C22.1, C23.1, C24.2, C25.2, D3.A, IC1.4 (GND), J5.2, J6.1, J6.S1 (SHIELD), J6.S2 (SHIELD), J10.6, J10.9, J10.14, J10.20, J10.25, J10.30, J10.34, J10.39, PS1.2 (GND), Q1.3, Q2.3, Q4.3, Q5.3, R1.1, R2.1, R6.2, R7.2, R9.2, R11.2, R12.2, R13.2, R15.2, R17.2, U1.1 (GND), U1.9 (GND), U2.2 (GND), U3.JP1_8 (EN), U3.JP2_2 (GND), U3.JP2_8 (GND), U4.JP1_8 (EN), U4.JP2_2 (GND), U4.JP2_8 (GND), U5.4 (GND), U5.9 (GND), U6.JP1_8 (EN), U6.JP2_2 (GND), U6.JP2_8 (GND), U7.4 (GND), U7.9 (GND), U8.4 (GND), U8.9 (GND), U9.4 (GND)
GPIO4: J9.11, J10.7
GPIO7: J9.4, J10.26
GPIO8: J9.5, J10.24
GPIO9: J9.9, J10.21
GPIO10: J9.10, J10.19
GPIO11: J9.8, J10.23
GPIO14: J9.6, J10.8
GPIO15: J9.7, J10.10
GPIO16: J9.3, J10.36
GPIO20: J9.2, J10.38
GPIO21: J9.1, J10.40
unnamed: C2.2, C3.2, F2.2, U1.5 (VM)
unnamed: C4.1, D1.C (2), D2.A
unnamed: C5.1, D3.K, F4.2, FB1.1
unnamed: C9.1, R7.1
unnamed: C9.2, U5.6 (COMP)
unnamed: C10.1, U5.2 (BOOT)
unnamed: C10.2, L2.1, U5.1 (SW)
unnamed: C11.2, C12.2, C13.2, IC2.6 (E1), L2.2, Q3.3, R8.1
unnamed: C19.1, R15.1
unnamed: C19.2, U8.6 (COMP)
unnamed: C20.1, U8.2 (BOOT)
unnamed: C20.2, L3.1, U8.1 (SW)
unnamed: D1.A (1), L1.2, TP2.1, U2.1 (SW)
unnamed: D2.K (C), R2.2, U2.3 (FB)
unnamed: F1.2, M1.2 (-)
unnamed: F3.2, R3.2
unnamed: F5.2, J7.1
unnamed: F6.2, J8.1
unnamed: IC1.2 (RX), IC1.3 (TX), J6.4
unnamed: IC1.5 (TY), IC1.6 (RY), J6.3
unnamed: IC2.1 (C1), IC2.2 (B1), IC2.3 (B2), R11.1
unnamed: IC2.4 (C2), Q3.1, R12.1
unnamed: J7.2, Q4.2
unnamed: J8.2, Q5.2
unnamed: JP1.1 (A), U9.7 (WP)
unnamed: M1.1 (+), Q1.2
unnamed: PE1.1, U1.8 (OUT2)
unnamed: PE1.2, U1.6 (OUT1)
unnamed: Q2.2, R3.1
unnamed: R1.2, U1.7 (ISEN)
unnamed: R6.1, U5.7 (RLIM)
unnamed: R8.2, R9.1, U5.5 (FB)
unnamed: R10.2, U5.3 (EN)
unnamed: R13.1, U8.7 (RLIM)
unnamed: R14.2, U8.3 (EN)
unnamed: R16.2, R17.1, U8.5 (FB)
unnamed: R21.1, U3.JP1_6 (MS2)
unnamed: R20.1, U3.JP1_7 (MS1)
unnamed: R23.1, U4.JP1_6 (MS2)
unnamed: R22.1, U4.JP1_7 (MS1)
unnamed: R25.1, U6.JP1_6 (MS2)
unnamed: R24.1, U6.JP1_7 (MS1)
PHADRV: J10.33, U7.6 (PH)
PWRGPIO1: J10.11, Q4.1
PWRGPIO2: J10.22, Q5.1
SCL: IC1.7 (SY), J10.5, R5.1
SDA: IC1.1 (SX), J10.3, R4.2
STEPFOCUS: J10.35, U6.JP1_2 (STEP)
STEPMAIN: J10.13, TP3.1, U3.JP1_2 (STEP)
STEPSEC: J10.18, TP4.1, U4.JP1_2 (STEP)

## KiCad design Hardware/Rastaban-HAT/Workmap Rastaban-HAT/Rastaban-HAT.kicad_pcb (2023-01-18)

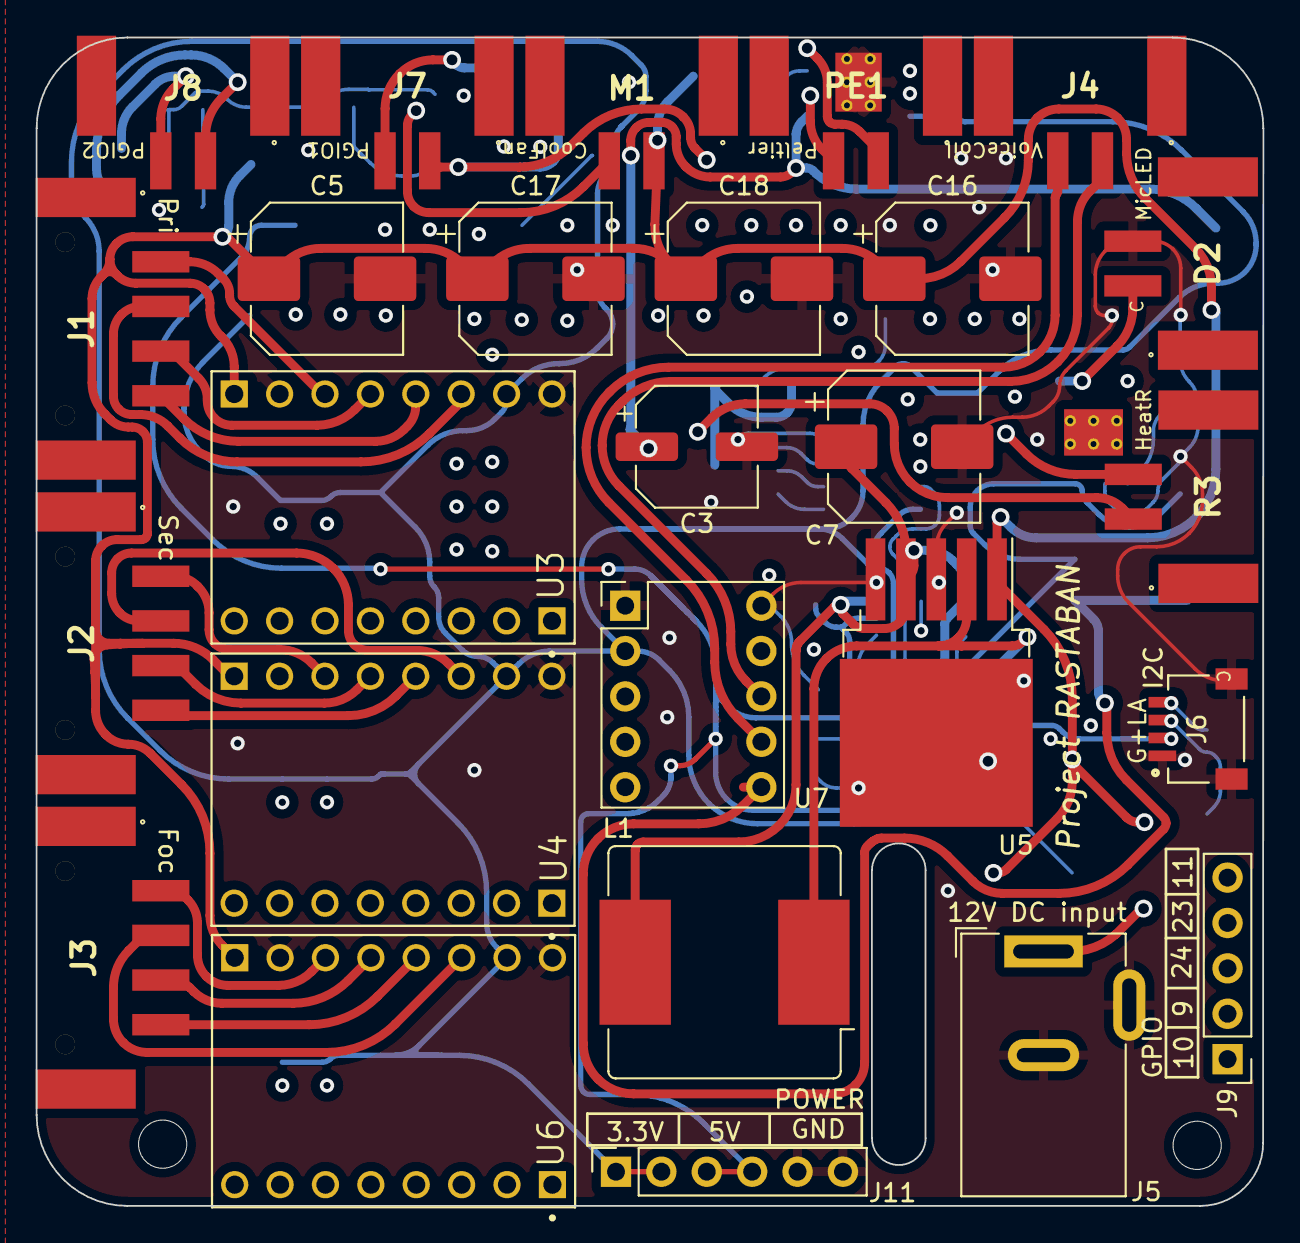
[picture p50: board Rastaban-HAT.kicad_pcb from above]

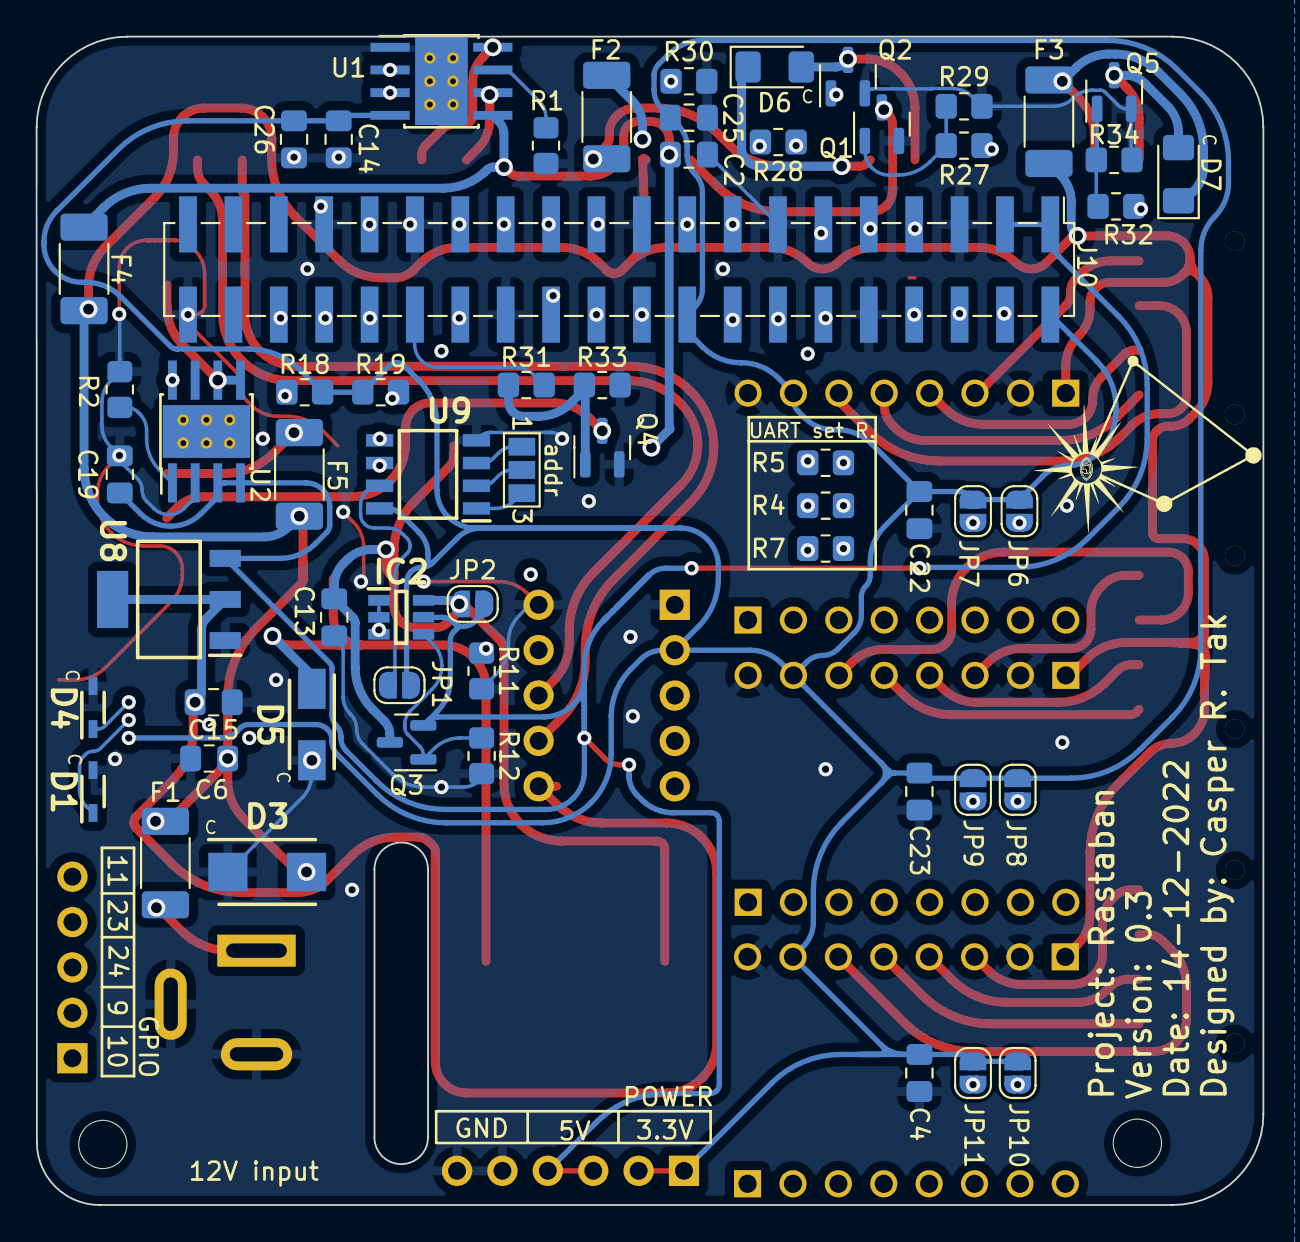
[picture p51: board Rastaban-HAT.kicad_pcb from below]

Board: 4 copper layers, 68.7 x 65.4 mm, 87 parts (59 on the bottom side), 75 nets.

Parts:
C2, C4, C6, C13, C14, C15, C22, C23, C25, C26: 100nF 50V; C_0805_2012Metric_Pad1.18x1.45mm_HandSolder
C3: 47uF 50V; CP_Elec_6.3x5.4
C5, C16, C17, C18: 100uF 50V; CP_Elec_8x10
C7: 220uF 50V; CP_Elec_8x10
C19: 10uF 50V; C_0805_2012Metric_Pad1.18x1.45mm_HandSolder
D1, D4: ESD7351HT1G; SOD2512X110N
D2: OVLEW1CB9; 1808190
D3: SMBJ26A; DIOM5436X261N
D5: SS54-HF; DIOM5025X220N
D6, D7: DIODE-1N4148; D_1206_3216Metric_Pad1.42x1.75mm_HandSolder
F1: 6A; Fuse_2010_5025Metric_Pad1.52x2.65mm_HandSolder
F2, F3: 3A; Fuse_2010_5025Metric_Pad1.52x2.65mm_HandSolder
F4, F5: 4A; Fuse_2010_5025Metric_Pad1.52x2.65mm_HandSolder
H3, H4: MountingHole; MountingHole_2.7mm_M2.5
IC2: BCM53DS; SOT95P280X145-6N
J1, J2, J3: 1778780
J4, J7, J8: Screw_Terminal_01x02; 1808190
J5: Jack-DC 12V+; BarrelJack_Wuerth_6941xx301002
J6: SM04B-SRSS-TB(LF)(SN); JST_SM04B-SRSS-TB(LF)(SN)
J9: Conn_01x05_Male; PinHeader_1x05_P2.54mm_Vertical
J10: GPIO; PinHeader_2x20_P2.54mm_Vertical_SMD
J11: Conn_01x06_Male; PinSocket_1x06_P2.54mm_Vertical
JP1: ID_WP; SolderJumper-2_P1.3mm_Open_RoundedPad1.0x1.5mm
JP2, JP6, JP7, JP8, JP9, JP10, JP11: Jumper_2_Open; SolderJumper-2_P1.3mm_Open_RoundedPad1.0x1.5mm
JP4: Jumper_3_Open; SolderJumper-3_P1.3mm_Open_Pad1.0x1.5mm_NumberLabels
L1: 33uH; L_Bourns_SRR1208_12.7x12.7mm
M1: Fan; 1808190
PE1: PeltierElement; 1808190
Q1, Q2, Q4, Q5: PMV15ENE; SOT-23
Q3: DMG2305UX-7; SOT-23
R1: 0.2; R_0805_2012Metric_Pad1.20x1.40mm_HandSolder
R2: 0; R_0805_2012Metric_Pad1.20x1.40mm_HandSolder
R3: 10W resistor; 1808190
R4, R5, R7, R27, R28, R31, R32: 1k; R_0805_2012Metric_Pad1.20x1.40mm_HandSolder
R11, R29, R30, R33, R34: 10k; R_0805_2012Metric_Pad1.20x1.40mm_HandSolder
R12: 47K; R_0805_2012Metric_Pad1.20x1.40mm_HandSolder
R18, R19: 3.9k; R_0805_2012Metric_Pad1.20x1.40mm_HandSolder
U1: DRV8870DDA; Texas_HTSOP-8-1EP_3.9x4.9mm_P1.27mm_EP2.95x4.9mm_Mask2.4x3.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
U2: CN5711; Texas_HTSOP-8-1EP_3.9x4.9mm_P1.27mm_EP2.95x4.9mm_Mask2.4x3.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
U3, U4, U6: TMC2209; MODULE_TMC2208_SILENTSTEPSTICK
U5: LM2596S -5.0; TO-263-5_TabPin3
U7: DRV8838 POLOLU
U8: TLV1117-33; SOT230P700X180-4N
U9: CAT24C256; SOIC127P600X175-8N

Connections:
3.3V+: C4.1, C14.1, C22.1, C23.1, C25.1, C26.2, J6.2, J10.2, J10.18, J11.1, J11.2, JP1.2 (B), JP6.1 (A), JP7.1 (A), JP8.1 (A), JP9.1 (A), JP10.1 (A), JP11.1 (A), R18.2, R19.1, U1.4 (VREF), U3.JP2_7 (VIO), U4.JP2_7 (VIO), U6.JP2_7 (VIO), U7.VCC, U9.8 (VCC)
5V+: C19.1, IC2.5 (E2), J10.1, J10.3, J11.3, J11.4, JP2.2 (B), Q3.2, U2.3 (VCC), U2.4 (VCC), U8.3 (VI)
12V+: C5.1, C6.1, C16.1, C17.1, C18.1, D3.K, F1.2, F2.1, F3.1, F4.1, F5.1, M1.1 (+), U3.JP2_1 (VM), U4.JP2_1 (VM), U5.1 (VIN), U6.JP2_1 (VM)
12VIN: F1.1, J5.1
/FluidMotors/M1APRI: J1.4, U3.JP2_5 (M1A)
/FluidMotors/M1ASEC: J2.4, U4.JP2_5 (M1A)
/FluidMotors/M1BPRI: J1.2, U3.JP2_6 (M1B)
/FluidMotors/M1BSEC: J2.2, U4.JP2_6 (M1B)
/FluidMotors/M2APRI: J1.3, U3.JP2_4 (M2A)
/FluidMotors/M2ASEC: J2.3, U4.JP2_4 (M2A)
/FluidMotors/M2BPRI: J1.1, U3.JP2_3 (M2B)
/FluidMotors/M2BSEC: J2.1, U4.JP2_3 (M2B)
/FocusMotors/M1AFOC: J3.4, U6.JP2_5 (M1A)
/FocusMotors/M1BFOC: J3.2, U6.JP2_6 (M1B)
/FocusMotors/M2AFOC: J3.3, U6.JP2_4 (M2A)
/FocusMotors/M2BFOC: J3.1, U6.JP2_3 (M2B)
/FocusMotors/out1: J4.2, U7.01 (OUT1)
/FocusMotors/out2: J4.1, U7.02 (OUT2)
CTRLFAN: J10.32, R27.1
CTRLHEAT: J10.30, R31.1
CTRLLED: J10.11, U2.8 (CE)
ENDRV: J10.31, U7.EN (ENABLE)
EnaFoc: J10.36, U6.JP1_8 (EN)
EnaPri: J10.14, U3.JP1_8 (EN)
EnaSec: J10.16, U4.JP1_8 (EN)
GND: C2.1, C3.2, C4.2, C5.2, C6.2, C7.2, C13.1, C14.2, C15.1, C16.2, C17.2, C18.2, C19.2, C22.2, C23.2, C25.2, C26.1, D1.2, D2.2 (C), D3.A, D4.2, D5.2, J5.2, J5.3, J6.1, J6.S1 (SHIELD), J6.S2 (SHIELD), J10.5, J10.10, J10.13, J10.19, J10.26, J10.29, J10.33, J10.40, J11.5, J11.6, Q1.2 (S), Q2.2 (S), Q4.2 (S), Q5.2 (S), R1.1, R2.1, R11.2, R12.2, R29.2, R30.2, R33.2, R34.2, U1.1 (GND), U1.9 (GND), U2.2 (GND), U3.JP2_2 (GND), U3.JP2_8 (GND), U4.JP2_2 (GND), U4.JP2_8 (GND), U5.3 (GND), U5.5 (~ON/OFF), U6.JP2_2 (GND), U6.JP2_8 (GND), U7.GND, U8.1 (GND), U9.4 (GND)
GPIO9: J9.2, J10.22
GPIO10: J9.1, J10.20
GPIO11: J9.5, J10.24
GPIO23: J9.4, J10.15
GPIO24: J9.3, J10.17
ID_SCL: J10.27, R19.2, U9.6 (SCL)
ID_SDA: J10.28, R18.1, U9.5 (SDA)
IN1: J10.23, U1.3 (IN1)
IN2: J10.25, U1.2 (IN2)
unnamed: C2.2, C3.1, F4.2, U1.5 (VM)
unnamed: C7.1, C13.2, IC2.6 (E1), JP2.1 (A), L1.2, Q3.3, U5.4 (FB)
unnamed: C15.2, U7.VM, U8.2 (VO), U8.4 (VO)
unnamed: D2.1 (A), U2.5 (LED), U2.6 (LED)
unnamed: D5.1, L1.1, U5.2 (OUT)
unnamed: D6.1 (C), F2.2, J7.1
unnamed: D6.2 (A), J7.2, Q2.3 (D)
unnamed: D7.1 (C), F3.2, J8.1
unnamed: D7.2 (A), J8.2, Q5.3 (D)
unnamed: F5.2, R3.2
unnamed: IC2.1 (C1), IC2.2 (B1), IC2.3 (B2), R11.1
unnamed: IC2.4 (C2), Q3.1, R12.1
unnamed: JP1.1 (A), U9.7 (WP)
unnamed: JP4.1 (A), U9.3 (A2)
unnamed: JP4.2 (C), U9.2 (A1)
unnamed: JP4.3 (B), U9.1 (A0)
unnamed: JP6.2 (B), U3.JP1_7 (MS1)
unnamed: JP7.2 (B), U3.JP1_6 (MS2)
unnamed: JP8.2 (B), U4.JP1_7 (MS1)
unnamed: JP9.2 (B), U4.JP1_6 (MS2)
unnamed: JP10.2 (B), U6.JP1_7 (MS1)
unnamed: JP11.2 (B), U6.JP1_6 (MS2)
unnamed: M1.2 (-), Q1.3 (D)
unnamed: PE1.1, U1.8 (OUT2)
unnamed: PE1.2, U1.6 (OUT1)
unnamed: Q1.1 (G), R27.2, R29.1
unnamed: Q2.1 (G), R28.2, R30.1
unnamed: Q4.1 (G), R31.2, R33.1
unnamed: Q4.3 (D), R3.1
unnamed: Q5.1 (G), R32.2, R34.1
unnamed: R1.2, U1.7 (ISEN)
unnamed: R2.2, U2.1 (iset)
PHADRV: J10.34, U7.PH
PWRGPIO1: J10.12, R28.1
PWRGPIO2: J10.21, R32.1
RX: J10.9, R4.2, R5.1, R7.1, U3.JP1_5 (PDN/UART2), U4.JP1_5 (PDN/UART2), U6.JP1_5 (PDN/UART2)
SCL: D1.1, J6.3, J10.6
SDA: D4.1, J6.4, J10.4
SLEEP: J10.8, U7.~sleep (SLEEP)
TX: J10.7, R4.1, R5.2, R7.2

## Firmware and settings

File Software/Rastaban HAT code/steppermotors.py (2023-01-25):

import time
import pigpio
from enums import State
import constants

"""
This code is used to control the TMC2209 stepper motors using step, dir and enable pins. This is the "legacy" way to control stepper motors. 
However, it is nowadays more common to control stepper motors via UART (sometimes in combination with step/dir/en), 
since this gives the user more control over the stepper motors and enables extra features. 
This code can not be used by PCB V0.3 (Only UART).
"""


class STEPPERMOTORS():

    def __init__(self, pi, EnableGPIOPin: int, DirGPIOPin: int, StepGPIOPin: int) -> None:
        self._pigpio = pi
        self._EnableGPIOPin: int = EnableGPIOPin
        self._DirGPIOPin: int = DirGPIOPin
        self._StepGPIOPin: int = StepGPIOPin
        self.state = None

    def SetMotorState(self, ENABLE: int):
        if ENABLE == 1:
            # low on enable pin to enable motordriver, tmc 2209
            self._pigpio.write(self._EnableGPIOPin, constants.OFF)
            self.state = State.MOTOR_ENABLED.name
            return self.state
        else:
            # high on enable pin to disable motordriver, tmc 2209
            self._pigpio.write(self._EnableGPIOPin, constants.ON)
            self.state = State.MOTOR_DISABLED.name
            return self.state

    def SetMotorDir(self, DIR: int):
        if DIR == 1:
            self._pigpio.write(self._DirGPIOPin, constants.ON)
            self.state = State.MOTOR_CLOCKWISE.name
            return self.state
        else:
            self._pigpio.write(self._DirGPIOPin, constants.OFF)
            self.state = State.MOTOR_COUNTERCLOCKWISE.name
            return self.state

    def SetMotorStep(self, STEP: int):
        for x in range(STEP):
            self._pigpio.write(self._StepGPIOPin, constants.ON)
            time.sleep(0.00005)
            self._pigpio.write(self._StepGPIOPin, constants.OFF)
            time.sleep(0.00005)
            print(x)


if __name__ == "__main__":

    PrimaryStepper = STEPPERMOTORS(
        pi=pigpio.pi(), EnableGPIOPin=21, DirGPIOPin=23, StepGPIOPin=27)
    SecondaryStepper = STEPPERMOTORS(
        pi=pigpio.pi(), EnableGPIOPin=20, DirGPIOPin=22, StepGPIOPin=24)
    FocusStepper = STEPPERMOTORS(
        pi=pigpio.pi(), EnableGPIOPin=16, DirGPIOPin=26, StepGPIOPin=19)

    print("Enable/Disable Motor")
    x = PrimaryStepper.SetMotorState(constants.OFF)
    print(x)
    time.sleep(1)
    x = PrimaryStepper.SetMotorState(constants.ON)
    print(x)
    time.sleep(1)

    x = FocusStepper.SetMotorState(constants.ON)
    print(x)
    time.sleep(1)

    print("Set Motor Direction Test")
    time.sleep(1)
    x = FocusStepper.SetMotorDir(1)
    print(x)

    print("Set Motor Step Test")
    time.sleep(1)
    x = FocusStepper.SetMotorStep(400)
    print(x)

    print("Set Motor Direction Test")
    time.sleep(1)
    x = FocusStepper.SetMotorDir(0)
    print(x)

    print("Set Motor Step Test")
    time.sleep(1)
    x = FocusStepper.SetMotorStep(400)
    print(x)

    print("Enable/Disable Motor")
    x = SecondaryStepper.SetMotorState(constants.OFF)
    print(x)
    time.sleep(1)
    x = SecondaryStepper.SetMotorState(constants.ON)
    print(x)
    time.sleep(1)

    print("Set Motor Direction Test")
    time.sleep(1)
    x = PrimaryStepper.SetMotorDir(1)
    print(x)

    print("Set Motor Direction Test")
    time.sleep(1)
    x = SecondaryStepper.SetMotorDir(1)
    print(x)

    print("Set Motor Step Test")
    time.sleep(1)
    x = SecondaryStepper.SetMotorStep(6400)
    print(x)

    print("Set Motor Step Test")
    time.sleep(1)
    x = PrimaryStepper.SetMotorStep(6400)
    print(x)

    print("Set Motor Direction Test")
    time.sleep(1)
    x = PrimaryStepper.SetMotorDir(0)
    print(x)

    print("Set Motor Step Test")
    time.sleep(1)
    # one rotation is 3200 pulses by microstepping 8. motor has 400 steps by full stepping
    x = PrimaryStepper.SetMotorStep(6400)
    print(x)

    print("Set Motor Direction Test")
    time.sleep(1)
    x = SecondaryStepper.SetMotorDir(0)
    print(x)

    print("Set Motor Step Test")
    time.sleep(1)
    # one rotation is 3200 pulses by microstepping 8. motor has 400 steps by full stepping
    x = SecondaryStepper.SetMotorStep(6400)
    print(x)

    x = PrimaryStepper.SetMotorState(State.OFF)
    print(x)

    x = SecondaryStepper.SetMotorState(constants.OFF)
    print(x)
    time.sleep(1)

    print("test complete")

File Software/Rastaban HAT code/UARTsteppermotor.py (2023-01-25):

import pigpio
from enums import State
import time
import constants
# Path to driver, important.
from TMC_2209_UART.src.TMC_2209_StepperDriver import *

"""
This code is used to control the TMC2209 stepper motors using UART.  
By using UART it is possible to set and read the parameters for the driver.
The goal of this code is to create control blocks for the library code.
"""


class UARTSTEPPERMOTOR(TMC_2209):

    def __init__(self, pi, EnableGPIOPin: int, DriverAddress: int) -> None:
        super().__init__(driver_address=DriverAddress, pin_en=EnableGPIOPin)
        self._pigpio = pi
        self._EnableGPIOPin: int = EnableGPIOPin
        self._driver_address: int = DriverAddress
        self.state = None

    def ControlMotorMovement(self, dirreg: bool, rpm: int, revolutions: float):
        self.set_direction_reg(dirreg)
        self.set_vactual_rpm(rpm, revolutions=revolutions)

    def SetMotorSettings(self, cur: int, interpol: bool, spread: bool, microstepres: int, interrsense: bool):
        self.set_current(cur)
        self.set_interpolation(interpol)
        self.set_spreadcycle(spread)
        self.set_microstepping_resolution(microstepres)
        self.set_internal_rsense(interrsense)

    def PrintCurrentDriverSettings(self):
        print("---\n---")  # for readability
        print("---CURRENTDRIVERSETTINGS---")  # for readability
        self.readIOIN()
        self.readCHOPCONF()
        self.readDRVSTATUS()
        self.readGCONF()
        print("---ENDING-CURRENTDRIVERSETTINGS---")  # for readability
        print("---\n---")  # for readability


if __name__ == "__main__":

    print("---")
    print("SCRIPT START")
    print("---")

    primarystepper = UARTSTEPPERMOTOR(
        pi=pigpio.pi(), EnableGPIOPin=27, DriverAddress=0)  # create object
    secondarystepper = UARTSTEPPERMOTOR(
        pi=pigpio.pi(), EnableGPIOPin=22, DriverAddress=1)  # create object
    focusstepper = UARTSTEPPERMOTOR(
        pi=pigpio.pi(), EnableGPIOPin=19, DriverAddress=2)  # create object

    primarystepper.SetMotorSettings(2000, True, True, 256, False)
    primarystepper.PrintCurrentDriverSettings()
    primarystepper.set_loglevel(Loglevel.DEBUG)
    primarystepper.set_movement_abs_rel(MovementAbsRel.ABSOLUTE)
    primarystepper.set_motor_enabled(True)
    primarystepper.ControlMotorMovement(True, 50, 3)
    time.sleep(1)
    primarystepper.ControlMotorMovement(False, 50, 3)
    primarystepper.set_motor_enabled(False)

    print("---\n---")  # for readability

    secondarystepper.SetMotorSettings(1200, True, True, 256, False)
    secondarystepper.PrintCurrentDriverSettings()
    secondarystepper.set_loglevel(Loglevel.DEBUG)
    secondarystepper.set_movement_abs_rel(MovementAbsRel.ABSOLUTE)
    secondarystepper.set_motor_enabled(True)
    secondarystepper.ControlMotorMovement(True, 150, 3)
    time.sleep(1)
    secondarystepper.ControlMotorMovement(False, 150, 3)
    secondarystepper.set_motor_enabled(False)

    print("---\n---")  # for readability

    focusstepper.SetMotorSettings(1000, True, True, 256, False)
    focusstepper.PrintCurrentDriverSettings()
    focusstepper.set_loglevel(Loglevel.DEBUG)
    focusstepper.set_movement_abs_rel(MovementAbsRel.ABSOLUTE)
    focusstepper.set_motor_enabled(True)
    focusstepper.ControlMotorMovement(True, 10, 1.5)  # focus motors up
    time.sleep(2)
    focusstepper.ControlMotorMovement(False, 10, 1.5)  # focus motors down
    focusstepper.set_motor_enabled(False)
    print("---\n---")  # for readability

primarystepper.deinit()
secondarystepper.deinit()
focusstepper.deinit()
del primarystepper
del secondarystepper
del focusstepper

print("---")
print("SCRIPT FINISHED")
print("---")

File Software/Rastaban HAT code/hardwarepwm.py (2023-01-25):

from enums import State
import constants

"""
This is the Hardware PWM class, only usable for hardware PWM pins on the RPI.
"""


class HARDWAREPWM():

    def __init__(self, pi, GPIOPin: int) -> None:
        self._GPIOPin: int = GPIOPin
        self._pigpio = pi
        self.state = None

    def TurnOn(self):
        self._pigpio.hardware_PWM(self._GPIOPin, constants.MAX, constants.MAX)
        self.state = State.ON.name
        return self.state

    def TurnOff(self):
        self._pigpio.hardware_PWM(self._GPIOPin, constants.OFF, constants.OFF)
        self.state = State.OFF.name
        return self.state

    def SetValue(self, DutyCycle: int, Frequency: int):
        self._pigpio.hardware_PWM(self._GPIOPin, Frequency, DutyCycle)
        self.state = State.CUSTOM.name
        return self.state

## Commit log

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2022-09-02 Updated and corrected LED schematic
    [WaterQualityMonitor-PI-HAT.kicad_sch]
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2022-09-07 removed old regulator circuits
    a better chip (tested) has been found rt7272a
    [First order list.xlsx, PowerManagementSystem.kicad_sch]
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2022-09-07 Finished Motor drivers and started PMS again
    Now I actually removed the power management system
    [FluidMotors.kicad_sch, FocusMotors.kicad_sch, PowerManagementSystem.kicad_sch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]
2022-09-07 placed components
    First L should be checked, possibly not the right component
    [FocusMotors.kicad_sch, PowerManagementSystem.kicad_sch, WaterQualityMonitor-PI-HAT.kicad_sch]
2022-09-08 Finished powermanagementsystem
    added RPI powersupply
    added 5V and 3.3V power supply
    changed some components (errors)
    [First order list.xlsx, FluidMotors.kicad_sch, LOG.xlsx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]
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2022-09-08 Enhanced schematics
    Moved protection circuits to main schematic
    changed tmc2208 VIO to 3.3V (5V is also fine)
    added fuses to heat and cooling schematic
    [3.3V&5.kicad_sch, FluidMotors.kicad_sch, FocusMotors.kicad_sch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]
2022-09-08 updated power management circuit
    also added extra notes to conversation 6.
    added datasheet.
    [RaspberryPiPower.kicad_sch, WaterQualityMonitor-PI-HAT.kicad_sch]
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2022-09-08 added breakout connector for i2c
    standard = qwiic connector (jst 4 pin)
    [WaterQualityMonitor-PI-HAT.kicad_sch]
2022-09-09 Updated designs
    changed some labels to correct ones (glob, hier, net, input, output)
    added H-bridge to peltier for cooling and heating functionality
    [3.3V&5.kicad_sch, FluidMotors.kicad_sch, FocusMotors.kicad_sch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]
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2022-09-12 documentation and schematic improvements
    documentation updated, design choices update on led driver
    added esd protection options diodes and ic for i2c esd protection
    [LOG.xlsx]
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2022-09-12 fixed i2c circuit
    [WaterQualityMonitor-PI-HAT.kicad_sch]
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2022-09-13 Updated H-bridge schematic + Use case diagram
    included decoupling capacitors
    Started working on use case diagram
    [LOG.xlsx, WaterQualityMonitor-PI-HAT.kicad_sch]
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2022-09-13 assigent footprints to all current components
    I chose 1206smd handsolderable for caps and resistors and inductors, may need to be revised
    [3.3V&5.kicad_sch, FluidMotors.kicad_sch, FocusMotors.kicad_sch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]
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2022-09-14 replaced old pi GPIO header & added ID_SDA&ID_SCL circuit
    New header matches pinout on pcb and is more clear
    [PI-HAT.kicad_pcb, PI-HAT.kicad_sch, WaterQualityMonitor-PI-HAT.kicad_sch]
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2022-09-14 added missing footprints
    [WaterQualityMonitor-PI-HAT.kicad_sch]
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2022-09-15 changed some RPI connection to hardware PINS
    DRV8838 likes hardware PWM on the ENABLE pin, so I changed the pin to gpio pin 13
    [WaterQualityMonitor-PI-HAT.kicad_sch]
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2022-09-19 enh schematic
    added power pins breakout
    replaced common ground with specific ground labels
    [3.3V&5.kicad_sch, FluidMotors.kicad_sch, FocusMotors.kicad_sch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]
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2022-09-19 Ran ERC
    fixed most errors (except for pwr plane issues)
    ignored most warnings
    [WaterQualityMonitor-PI-HAT.kicad_sch]
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2022-09-22 first changes to V1.0 Schematic (after jeroen's feedback)
    Removed 5.0V&3.3V power line
    changed values in RPI 5V power line
    [3.3V&5.kicad_sch, RaspberryPiPower.kicad_sch, Rastaban-HAT.kicad_sch]
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2022-09-22 updated all ground lables to common ground
    switched back from power grounds, since they are not possible (stepper drivers)
    [FluidMotors.kicad_sch, FocusMotors.kicad_sch, RaspberryPiPower.kicad_sch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]
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2022-09-22 Replaced old LED driver circuit with simpeler one
    Advice from jeroen implemented
    [Rastaban-HAT.kicad_sch]
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2022-09-27 fixed eeprom esd protection
    [LOG.xlsx, Rastaban-HAT.kicad_sch]
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2022-09-29 Schematic v1.2
    added johan brussen's advice
    written software for stepper motor drivers
    test report written.
    [FluidMotors.kicad_sch, FocusMotors.kicad_sch, LOG.xlsx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]
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2022-10-04 python book, kicad plugin
    Added python book
    installed kicad plugin that saves hours of time finding LCSC parts for pcb assembly (kicad jlcpcb tools)
    [LOG.xlsx, mapping.csv]
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2022-10-04 ERC fixed on schematic
    [FluidMotors.kicad_sch, FocusMotors.kicad_sch, Rastaban-HAT.kicad_pcb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]
2022-10-05 removed warnings in PCB new by fixing footprints
    [FluidMotors.kicad_sch, FocusMotors.kicad_sch, LOG.xlsx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]
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2022-10-12 changed all capacitor voltages to 50V
    This makes ordering and component selection easier.
    [FluidMotors.kicad_sch, FocusMotors.kicad_sch, RaspberryPiPower.kicad_sch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]
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2022-10-13 trying to fix git
    [Rastaban-HAT.kicad_sch]
2022-10-13 fixed github and updated pcb
    Fixed github by deleting head and main in origin map
    [Rastaban-HAT.kicad_pcb, Rastaban-HAT.kicad_sch]
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2022-10-13 bom file fixed
    [Rastaban-HATbomv1.csv]
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2022-10-17 ERC finished
    0 errors
    0 warnings (some exclusions made)
    [Rastaban-HAT.kicad_pcb]
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2022-10-31 Worked on presentation and wiring pcb
    ERC: 0 error, 30 warnings
    [LOG.xlsx, Rastaban-HAT.kicad_pcb]
2022-10-31 fixed more ERC warnings
    Problem with net parity tbf
    [Rastaban-HAT.kicad_pcb]
2022-10-31 fixed parity problem ERC: 0 err 0 war
    [FocusMotors.kicad_sch, Rastaban-HAT.kicad_pcb, Rastaban-HAT.kicad_sch]
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2022-10-31 added silkscreen on back
    added useful board information
    added logo to files
    [Rastaban-HAT.kicad_pcb]
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2022-11-01 fixed max value bug
    [pwm.py]
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2022-11-01 fixed missing gpio pin
    [peltier.py]
2022-11-01 Trying to fix SetTemp
    [peltier.py]
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2022-11-01 Swapped frequency and dutycycle (cause of error)
    [peltier.py]
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2022-11-02 trying to fix unit test 1
    [motors.py]
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2022-11-02 fixing unit tests motors (changing numbers and names)
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2022-11-02 fixed the huge problem
    Everything from software was overwritten and broken.
    [enums.py, fan.py, heatingresistor.py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]
2022-11-02 trying to fix stepper motor errors (no permission to update gpio)
    [steppermotors.py]
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2022-11-08 fixed enable, disable confusion
    [steppermotors.py]
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2022-11-17 added i2c esd error to word doc
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2022-11-21 Started on V0.2 PCB and V1.3 schematic
    -added new power circuit for RPI (removed old one rt7272)
    -made daughter schematics sheets smaller
    [FluidMotors.kicad_sch, FocusMotors.kicad_sch, RaspberryPiPower.kicad_sch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]
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2022-11-21 started on V0.2 schematic fixes
    -fixed vcc on drv8838
    -added bypass to backpower protection circuit rpi
    -removed unnecessary capacitors
    -removed esd ic's
    -added esd tvs diodes
    -made schematic more readable
    -fixed u7 in pcb new(see point 1)
    -changed enable focus to hierarchal flag
    -stepper motors are 12V only now (removed jumper)
    -removed testpoints
    [FluidMotors.kicad_sch, FocusMotors.kicad_sch, Fourth order rastaban-HAT .csv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]
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2022-11-22 ERC errors resolved
    [Rastaban-HAT.kicad_pcb]
2022-11-22 resolved important warnings
    [Rastaban-HAT.kicad_pcb]
2022-11-22 Added silkscreen to buttom header (and figured out that header was wrong, again)
    [Rastaban-HAT.kicad_pcb]
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2022-11-22 removed edge cut error.
    [Rastaban-HAT.kicad_pcb]
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2022-11-22 fixed github
    [FluidMotors.kicad_sch, FocusMotors.kicad_sch, Rastaban-HAT.kicad_pcb]
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2022-11-22 High power lines routed
    -i think i got them all at least. width 0.600mm
    [Rastaban-HAT.kicad_pcb]
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2022-11-22 ERC: errors resolved
    [Rastaban-HAT.kicad_pcb]
2022-11-22 ERC cleared
    - 0 errors
    - 0 warnings
    [Rastaban-HAT.kicad_pcb]
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2022-11-24 started working on V1.4
    -changed some footprints
    -added/changed some LCSC values to/for components
    [FocusMotors.kicad_sch, Fourth order rastaban-HAT .csv, LOG.xlsx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]
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2022-11-30 added doc files
    -stepper motor water resolution test report
    -tmc2209 datasheets and notes
    -pcb v0.3 improvements
    [LOG.xlsx]
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2022-12-05 Wrote documentation and finally got the multiple stepper drivers working on uart
    [FocusMotors.kicad_sch, LOG.xlsx]
2022-12-07 changed main and motor schematics
    MAIN:
    -removed some caps
    -changed cap values to 50v (for consistency)
    -removed FB1
    MOTORS:
    -Started replacing the 2208 with the TMC2209
    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
    [FluidMotors.kicad_sch, FocusMotors.kicad_sch, Rastaban-HAT.kicad_sch]
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2022-12-07 fixed the annotation bug
    [FluidMotors.kicad_sch, FocusMotors.kicad_sch, Rastaban-HAT.kicad_pcb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]
2022-12-08 changed some component values in RPI power circuit
    New components
    -lm2596s -5.0
    -ss510
    Removed:
    feedback resistors
    [RaspberryPiPower.kicad_sch, Rastaban-HAT.kicad_sch]
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2022-12-08 added tmc2208 footprints to 2209 schematic symbol
    interchangable since the TMC drivers have roughly the same pinout.
    [FluidMotors.kicad_sch, FocusMotors.kicad_sch, RaspberryPiPower.kicad_sch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]
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2022-12-08 Removed Enable control from stepper drivers and started V0.3 pcb redesign
    [FluidMotors.kicad_sch, FocusMotors.kicad_sch, Rastaban-HAT.kicad_pcb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]
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2022-12-08 swapped cooling fan en PGIO position
    [Rastaban-HAT.kicad_pcb]
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2022-12-12 wiring complete
    ERC
    errors: 0
    warnings: 17
    [Rastaban-HAT.kicad_pcb]
2022-12-12 Resolved some ERC warnings
    only warnings left are on stepper motor drivers, i can ignore those.
    [Rastaban-HAT.kicad_pcb, Rastaban-HAT.kicad_sch]
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2022-12-12 reverted manually and added rounded traces design V0.3
    [Rastaban-HAT.kicad_pcb]
2022-12-12 Started 4 layer board
    wired high power lanes for steppers and other outputs
    [Rastaban-HAT.kicad_pcb]
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2022-12-12 4 layer PCB finished
    Error: 0
    Warnings: 18
    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
    [Rastaban-HAT.kicad_pcb]
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2022-12-13 worked on PCB and schematic designs
    many small changes and some big schematic changes (motors)
    [FluidMotors.kicad_sch, FocusMotors.kicad_sch, RaspberryPiPower.kicad_sch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]
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2023-01-10 worked on PCB V0.3.1, improvements V0.4 Doc
    -flipped 3d orientation dr8838
    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
    [Rastaban-HAT.kicad_pcb]
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2023-01-17 update on uart final fix in documentation!
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2023-01-18 fixed path for uart oop code
    [UARTsteppermotor.py]
2023-01-18 tried code fix for uart
    [UARTsteppermotor.py]
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2023-01-19 Fixed the stepper motor issues with UART
    -documentation on fix added
    -updated scripts to work with uart
    -added uart logic analyser data for documentation
    [steppermotors.py]
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2023-01-19 fixed bug uartstep
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
